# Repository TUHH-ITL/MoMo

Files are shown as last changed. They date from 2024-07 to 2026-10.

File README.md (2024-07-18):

# MoMo

This is the repository of **MoMo**: An Open-Source **Mo**dular **Mo**bile Robot.

Find more information about MoMo in the [official documentation](https://tuhh-itl.github.io/MoMo/).

## License

The codes and files in this repository are under the [3-Clause BSD License](https://opensource.org/license/bsd-3-clause).

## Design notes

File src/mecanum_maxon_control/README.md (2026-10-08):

# Mecanum Maxon control

This package converts ROS 2 `geometry_msgs/Twist` commands on `/cmd_vel` to four
Maxon EPOS4 profile-velocity targets through `ros2_canopen`.

Wheel order and CAN node mapping:

1. front-left (`cia402_device_1`)
2. front-right (`cia402_device_2`)
3. rear-left (`cia402_device_3`)
4. rear-right (`cia402_device_4`)

The checked-in controller configuration contains the dimensions, 21:1 gearbox
ratio, node order, and motor directions verified on this MoMo robot.
The motor command clamp is 3000 RPM (about 1.50 m/s straight-line speed), below
the 3170 RPM maximum profile velocity configured in all four EPOS4 DCF files.

## Build

The matching `ros2_canopen` source is vendored in this workspace at
`src/ros2_canopen`. No files outside this workspace are needed at build time or
runtime.

Install the native build and teleoperation dependencies once:

```bash
sudo apt update
sudo apt install -y libtool libtool-bin libboost-all-dev \
  ros-jazzy-diagnostic-updater ros-jazzy-joy ros-jazzy-teleop-twist-joy
```

```bash
cd /home/itlbot2/ros2_jazzy
source /opt/ros/jazzy/setup.bash
# Overlay any packages already built in this workspace.
source install/setup.bash 2>/dev/null || true
colcon build --symlink-install \
  --base-paths src/ros2_canopen src/mecanum_maxon_control \
  --packages-up-to mecanum_maxon_control \
  --cmake-clean-cache
source install/setup.bash
```

Source `/opt/ros/jazzy/setup.bash` first in every new terminal. Otherwise CMake
cannot discover system ROS packages such as `diagnostic_updater`.

## CAN and launch

### After every PC reboot

`can0` is now brought up automatically by the systemd unit checked in at
`systemd/can0-up.service` in this package. It is bound to the udev-generated
device unit for the Kvaser adapter (`sys-subsystem-net-devices-can0.device`),
so it runs on every boot and every hotplug/replug of the adapter, configuring
`can0` at 1 Mbit/s with `restart-ms 100` before anything else needs it. No
manual step is required before launching ROS 2.

Install it on a new PC with:

```bash
sudo cp systemd/can0-up.service /etc/systemd/system/can0-up.service
sudo systemctl daemon-reload
sudo systemctl enable --now can0-up.service
```

Check it came up correctly:

```bash
systemctl status can0-up.service
ip -details -statistics link show can0
```

The last command must show `can0` as `UP` and bitrate `1000000`. If `can0` does
not exist at all, verify the Kvaser USB adapter is connected
(`lsusb | grep -i kvaser`), then run `sudo modprobe kvaser_usb`.

To force a manual re-bounce of the interface (e.g. after a CAN bus fault),
either restart the unit or run the equivalent commands directly:

```bash
sudo systemctl restart can0-up.service
# equivalent to:
sudo ip link set can0 down 2>/dev/null || true
sudo ip link set can0 type can bitrate 1000000 restart-ms 100
sudo ip link set can0 up
ip -details -statistics link show can0
```

No separate EPOS4 initialization command is required. The launch file resets,
configures, starts, and enables all four CANopen drives. Once `can0` is up, launch:

```bash
source /opt/ros/jazzy/setup.bash
source /home/itlbot2/MoMo/install/setup.bash
ros2 launch mecanum_maxon_control mecanum_drive.launch.py
```

Wait for this message before publishing `/cmd_vel`:

```text
All four EPOS4 drives initialized in profile velocity mode
```

The CANopen container needs raw SocketCAN access (`CAP_NET_RAW`/`CAP_NET_ADMIN`),
granted via a file capability on the built binary rather than running the whole
launch as root. Without it, `device_container_node` aborts on startup with
`CanController: Operation not permitted`.

Running everything as your normal user (instead of `sudo -E`) matters beyond
convenience: DDS discovery breaks across UIDs. FastDDS's shared-memory
transport creates separate `/dev/shm/fastrtps_*` segments per user, so
root-launched nodes and non-root `ros2` CLI tools (`ros2 node list`,
`ros2 topic echo`, `rqt`, etc.) silently can't see each other even though data
still flows fine *between* same-UID nodes.

**The capability must be re-applied after every rebuild** of `canopen_core`
(colcon reinstalling the binary wipes the capability bit — this happens even
with `--symlink-install`, since that flag symlinks scripts/config but still
*copies* compiled executables). This is now automatic:
`canopen_core/CMakeLists.txt` runs
`canopen_core/scripts/set_can_capabilities.sh` via `install(CODE ...)`,
directly on `install/canopen_core/lib/canopen_core/device_container_node`
once that file exists at its final path.

The script calls `sudo -n setcap` (non-interactive), so it needs a one-time
NOPASSWD sudoers rule scoped to that exact command on a new machine:

```bash
echo "$USER ALL=(root) NOPASSWD: /usr/sbin/setcap cap_net_admin,cap_net_raw+ep $(pwd)/../../install/canopen_core/lib/canopen_core/device_container_node" \
  | sudo EDITOR='tee -a' visudo -f /etc/sudoers.d/momo-can-capabilities
sudo visudo -c
```
(run from `src/mecanum_maxon_control`, or substitute the absolute install
path directly). `visudo -c` must report "parsed OK" — if not, remove
`/etc/sudoers.d/momo-can-capabilities` and fix it before doing anything else,
since a broken sudoers file can lock out `sudo` entirely.

Without that sudoers rule the build still succeeds — the script just prints a
warning and leaves the binary without the capability, same failure as before.
Verify manually any time with:

```bash
getcap install/canopen_core/lib/canopen_core/device_container_node
```

File capabilities put the binary into the dynamic linker's "secure-execution
mode" (the same rule as setuid binaries), which makes `ld.so` **ignore
`LD_LIBRARY_PATH`** — so `device_container_node` can no longer find workspace
libraries (e.g. `libcanopen_interfaces__rosidl_generator_c.so`) through the
`LD_LIBRARY_PATH` that `install/setup.bash` sets. Fixed by registering every
built package's `lib/` dir with `ldconfig` instead, which isn't an env var and
works regardless of secure-execution mode:

```bash
find /home/itlbot2/MoMo/install -mindepth 2 -maxdepth 2 -type d -name lib | sort \
  | sudo tee /etc/ld.so.conf.d/momo-ros2.conf
sudo ldconfig
```

Re-run this whenever a **new package** (not just a rebuilt one) is added to
the workspace, so its `lib/` dir gets picked up too.

Initial PDO setup can take about 30 seconds; the `cmd_vel` controller starts
after a 45-second safety delay.

Test at low speed with all wheels clear of the floor:

```bash
ros2 topic pub --once /cmd_vel geometry_msgs/msg/Twist \
  "{linear: {x: 0.05, y: 0.0}, angular: {z: 0.0}}"
```

The controller latches the last velocity until a new command arrives. The joystick
teleoperation node sends a zero command when its enable button is released, so the
robot stops even though the underlying controller uses latched commands.

### Logitech F710 joystick

Connect the F710 USB receiver, put the switch on the front of the gamepad in `X`
(XInput) mode, and turn the gamepad on. Verify Linux can see it before launching:

```bash
lsusb | grep -i logitech
ls -l /dev/input/js*
```

The configuration is taken from the original MoMo backup:

- Hold **LB** (button 4) for normal driving (up to 1.0 m/s and 1.5 rad/s).
- Hold **RB** (button 5) for turbo driving (up to 1.5 m/s and 2.0 rad/s).
- Left stick up/down controls forward/reverse (`linear.x`).
- Left stick left/right controls mecanum strafing (`linear.y`).
- Right stick left/right controls rotation (`angular.z`).
- Release LB or RB to stop.

The launch file starts CANopen motor control, the joystick driver, and the joystick
to `/cmd_vel` converter together. Run it instead of `mecanum_drive.launch.py`:

```bash
source /opt/ros/jazzy/setup.bash
source /home/itlbot2/MoMo/install/setup.bash
ros2 launch mecanum_maxon_control mecanum_teleop.launch.py
```

Wait for `All four EPOS4 drives initialized in profile velocity mode` before
driving. If `/dev/input/js0` is absent, reconnect the receiver, confirm the pad is
in X mode, and press a gamepad button. The ROS 2 joystick driver selects joystick
device 0 by default.

### Changing joystick speed

Joystick speed is controlled in
`mecanum_maxon_control/config/teleop_joy.yaml`:

- `scale_linear.x` and `scale_linear.y` are the LB translation limits in m/s.
- `scale_angular.yaw` is the LB rotation limit in rad/s.
- `scale_linear_turbo.x` and `scale_linear_turbo.y` are the RB turbo
  translation limits in m/s.
- `scale_angular_turbo.yaw` is the RB turbo rotation limit in rad/s.

The controller also applies a final motor-speed ceiling using `max_motor_rpm` in
`mecanum_maxon_control/config/controller.yaml`. With the configured 21:1 gearbox
and 0.10 m wheel radius, 1000 motor RPM is approximately 0.50 m/s and the current
3000 RPM limit is approximately 1.50 m/s. Increasing only the joystick scales
above that limit will not make the wheels turn faster.

Do not set `max_motor_rpm` above the EPOS4 `max profile velocity` of 3170 RPM
configured in the four motor DCF files. After changing either YAML file, rebuild
and restart the launch file:

```bash
cd /home/itlbot2/ros2_jazzy
source /opt/ros/jazzy/setup.bash
source install/setup.bash
colcon build --symlink-install --packages-select mecanum_maxon_control
source install/setup.bash
```

Acceleration and stopping response are controlled by `max_wheel_acceleration`
and `max_wheel_deceleration` in `config/controller.yaml`, with the corresponding
EPOS profile objects `0x6083` and `0x6084` in
`config/maxon_mecanum_bus/bus.yml`. Both currently correspond to approximately
10000 motor RPM/s, giving approximately 0.3 seconds to reach maximum speed or
stop from it. Keep each software limit consistent with its EPOS limit when
tuning the response.

These 10000 RPM/s acceleration and deceleration values were tested on the MoMo
robot and produced responsive driving without the previous slow takeoff or the
wheels continuing to spin after releasing the joystick. For reference, the old
2000 RPM/s values took approximately 1.5 seconds to accelerate to or stop from
the 3000 RPM maximum. Test future changes with the wheels clear of the floor
before driving on the ground.

For keyboard control, leave `mecanum_drive.launch.py` running and use:

```bash
ros2 run teleop_twist_keyboard teleop_twist_keyboard
```

Use `k` or the space bar to send zero velocity and stop the robot.

Mecanum strafing uses `linear.y`; forward/reverse uses `linear.x`; rotation uses
`angular.z`.

## LED / speaker status indicator

`arduino_status_indicator.py` runs alongside the drive controller (launched by
`mecanum_drive.launch.py`) and drives the robot's LED strips and speaker
Arduino (`src/arduino/main`) over USB serial. It replaces the old behavior
where the Arduino played "Ich bin bereit" the instant it got power and ran a
decorative rainbow animation instead of showing anything meaningful.

There are two independent color sources, and the Arduino's own hardware
sensing always wins over ROS:

- **Hardware layer** (local to the Arduino sketch): reads the two
  battery-watcher pins directly and forces RED (shutdown/e-stop) or ORANGE
  (battery warning), regardless of what ROS is doing.
- **ROS layer** (this node): only shown while the hardware layer reports "no
  alarm". Reflects the `mission_control` state machine's active features.

The node subscribes to:

- `motors_ready` (published by `mecanum_epos4_controller.py` once all four
  EPOS4 drives are initialized) — sends `'R'` once so the Arduino announces
  "Ich bin bereit" at the right time instead of immediately on power-up.
- `mission_control/state_change` — maps `active_features` to a single color
  byte, checked in priority order:

| Active feature | Byte sent | Color | Meaning |
|---|---|---|---|
| `gentle_stop` | `'E'` | RED | safety stop (obstacle / software e-stop) |
| `accept_remote_drive_commands` | `'B'` | BLUE | joystick/teleop has control |
| `command_movement` | `'G'` | GREEN | actively driving a mission |
| *(none of the above)* | `'Y'` | YELLOW | idle, paused, or waiting for controller |

Before the state machine has published anything at all, the Arduino defaults
to **WHITE** on its own (no byte needs to be sent for this — it's the
sketch's power-on default), so the LEDs never silently show green before the
robot is actually doing anything.

Configured via the `status_indicator_port` launch argument (default
`/dev/ttyArduinoStatus`, `mecanum_drive.launch.py`). No udev rule exists yet
for this Arduino — add one under
`robotics_base/hardware_description/files/udev/`, following the existing
`44-rfid.rules`/`43-weighing_scale.rules` pattern, once the board's
`idVendor`/`idProduct` (and `serial` if it collides with another board) are
known from `udevadm info -a -n /dev/ttyACMx`. Until then the port name is
whatever the kernel assigns and can change across reboots/replugs.

## MoMo drivetrain calibration

The controller uses the dimensions and conversion from the original MoMo ROS 1
configuration: 0.10 m wheel radius, 0.54 m wheelbase, 0.58 m track width, and a
21:1 motor-to-wheel reduction. CANopen nodes 1 through 4 correspond to
front-left, front-right, rear-left, and rear-right respectively.

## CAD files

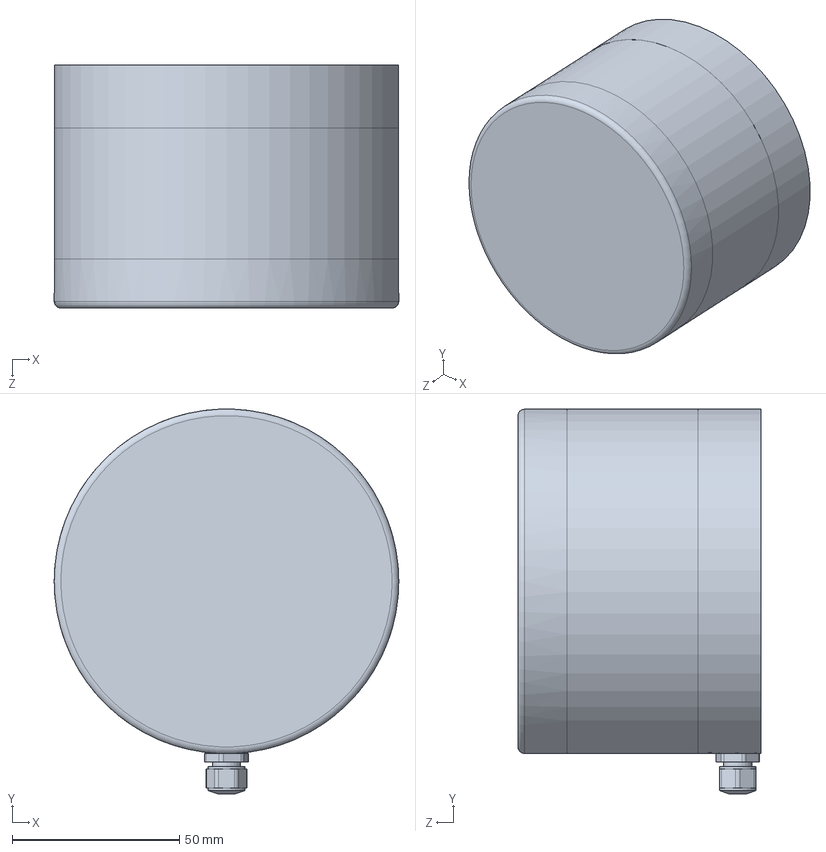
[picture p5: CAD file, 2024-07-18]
CAD/velodyne-vlp16.SLDPRT
103.0 x 115.1 x 72.7 mm

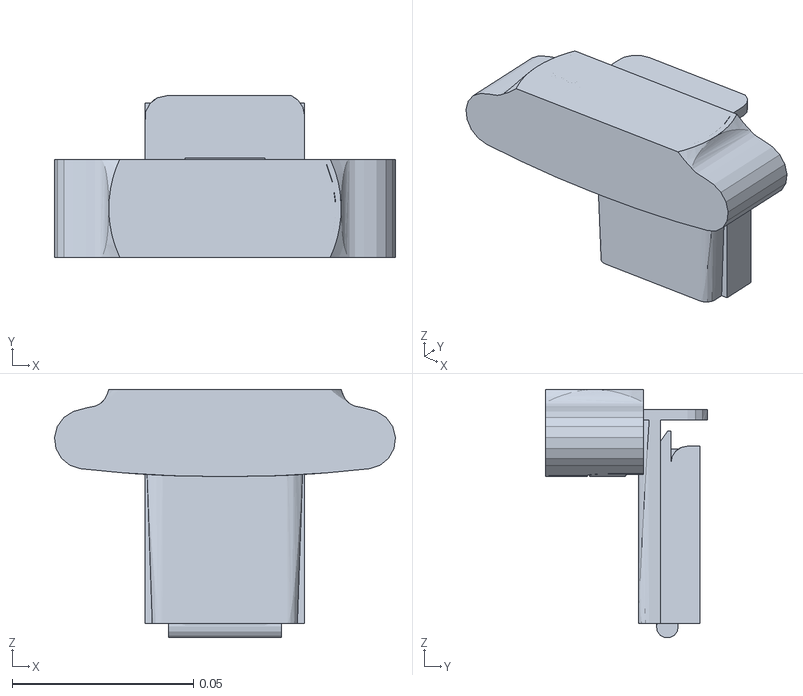
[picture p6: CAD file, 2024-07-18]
src/momo_description/meshes/collision/right_logitech.STL
0.094 x 0.0445 x 0.0684

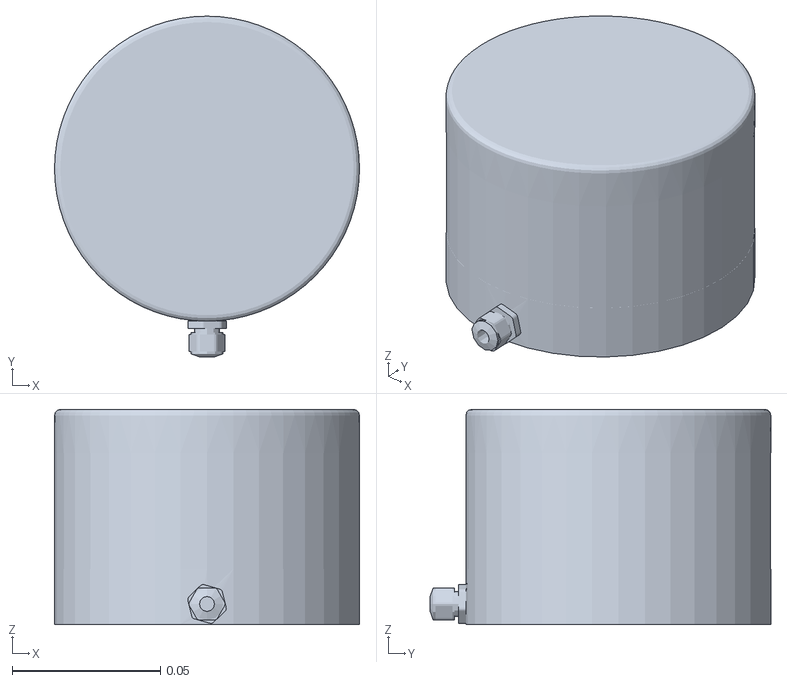
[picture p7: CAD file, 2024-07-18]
src/momo_description/meshes/visual/lidar.STL
0.103 x 0.115 x 0.0727

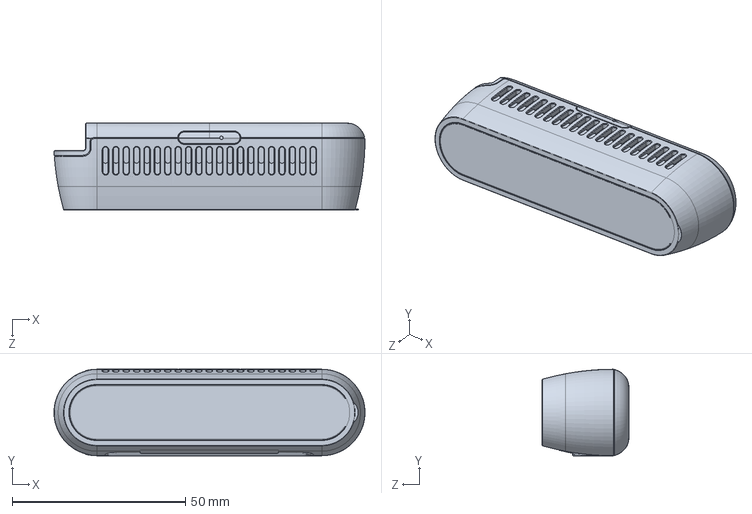
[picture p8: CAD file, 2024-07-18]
CAD/realsense_d435i.SLDPRT
89.9 x 25.0 x 25.1 mm

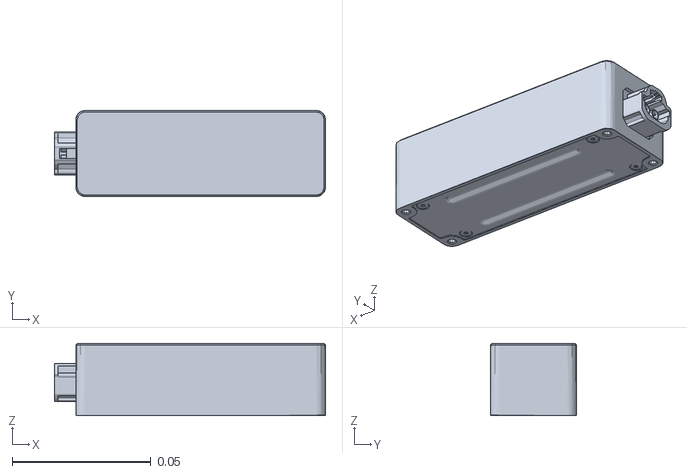
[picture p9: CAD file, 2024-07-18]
src/momo_description/meshes/collision/ifm_camera.STL
0.0977 x 0.031 x 0.026

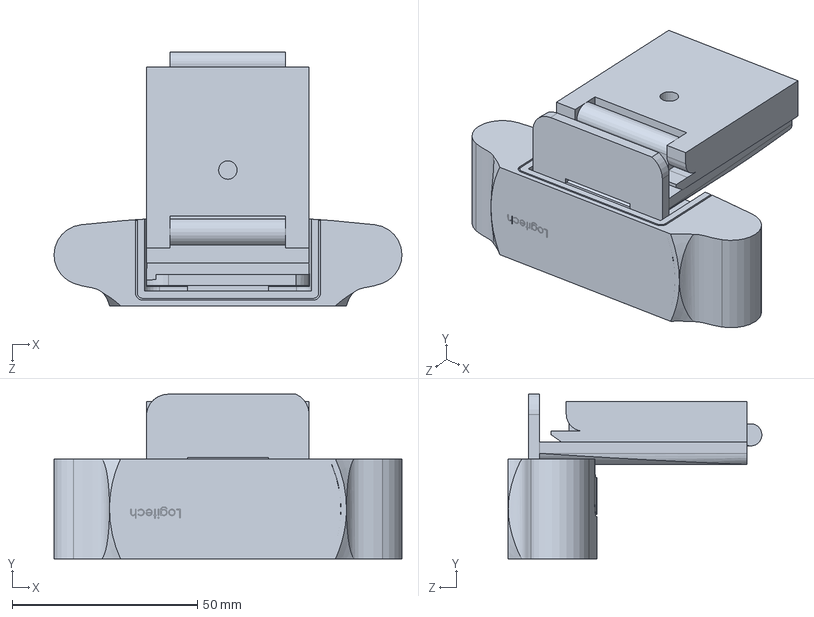
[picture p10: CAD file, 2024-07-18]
CAD/logitech_c920__link.SLDPRT
94.0 x 44.5 x 68.5 mm

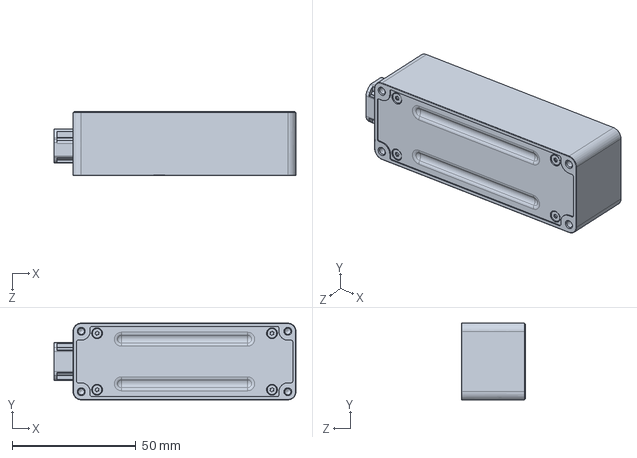
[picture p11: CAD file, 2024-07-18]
CAD/ifm_o3r222.SLDPRT
97.7 x 31.0 x 26.0 mm

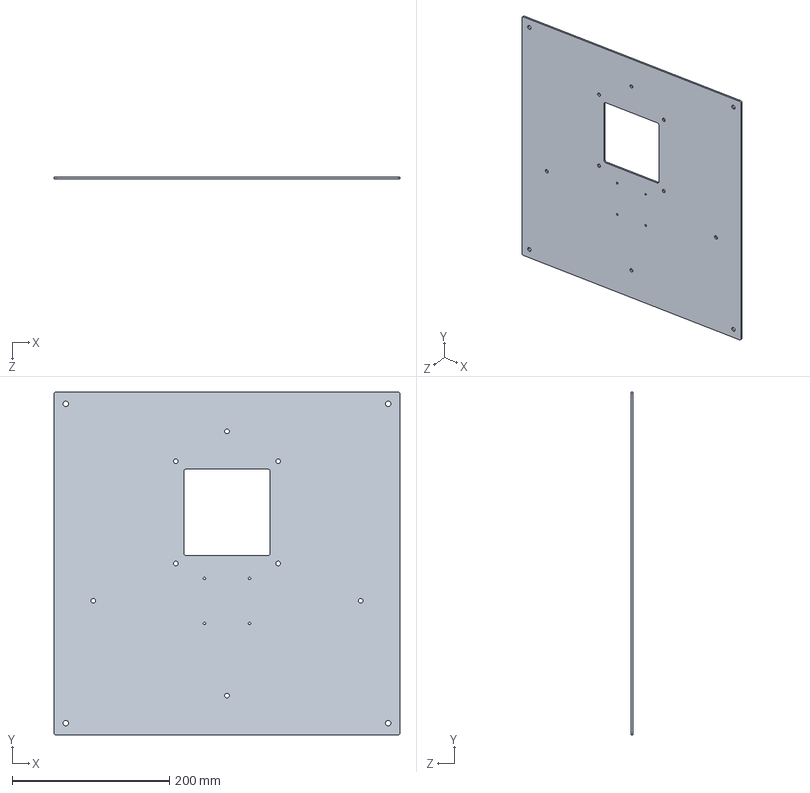
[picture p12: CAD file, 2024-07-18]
CAD/top_plate_localization_module.SLDPRT
440.0 x 436.0 x 3.00 mm

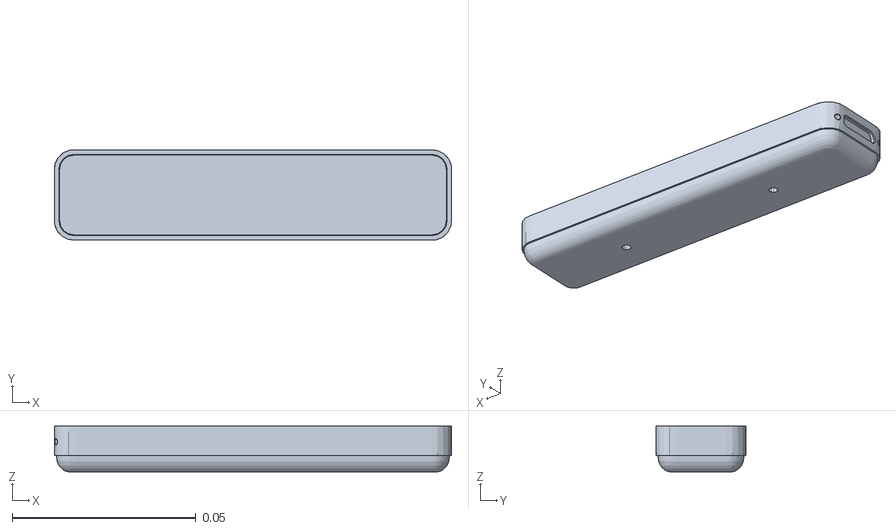
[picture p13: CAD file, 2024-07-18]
src/momo_description/meshes/visual/realsense_t265.STL
0.108 x 0.0245 x 0.0125

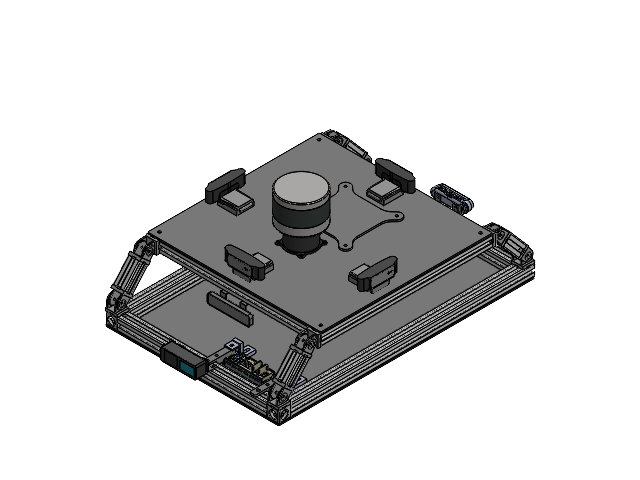
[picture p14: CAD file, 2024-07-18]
CAD/Assemblies/localization-module.SLDASM
base_plate_localization_module
cube_connector x 2
Aluminium_profile_620 x 2
Aluminium_profile_380 x 4
joint_30 x 16
Aluminium_profile_60 x 4
Aluminium_profile_436 x 2
top_plate_localization_module
cover_top_plate
velodyne_mount
velodyne-vlp16
logitech_c920__link x 4
realsense_mounting_bracket x 6
ifm_o3r222
realsense_t265
realsense_d435i
Mount_Harting_Connector x 2
Harting_Modular_Connector_upper_part
Aluminium_angle_bracket x 4
angle_5_20 x 2
mounting_bracket x 2

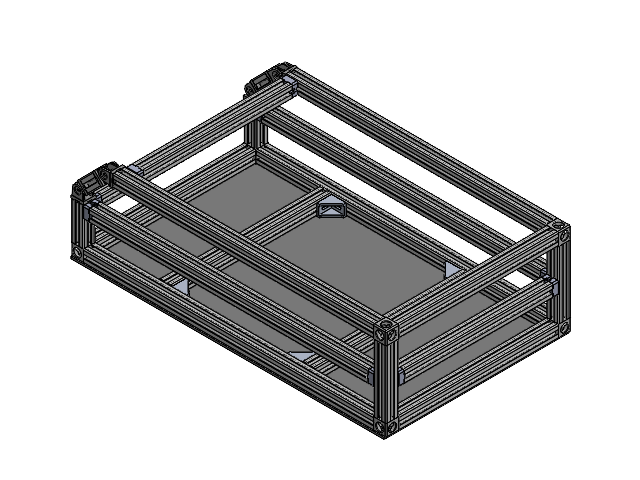
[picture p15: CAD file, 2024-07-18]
CAD/Assemblies/momo_frame.SLDASM
base_link
cube_connector x 6
Aluminium_profile_690 x 2
Aluminium_profile_380 x 5
Aluminium_profile_160 x 2
connector x 10
Aluminium_profile_664 x 2
Aluminium_profile_90 x 2
joint_30 x 8
Aluminium_profile_42_8 x 2
Aluminium_profile_620 x 2
Aluminium_profile_354 x 3
Aluminium_angle_bracket x 4

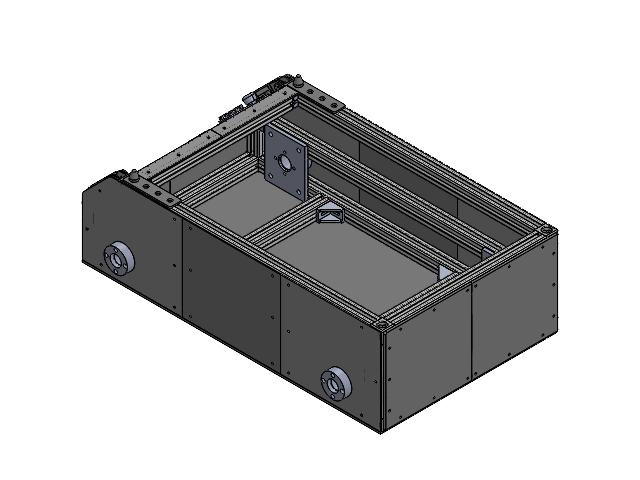
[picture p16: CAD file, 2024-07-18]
CAD/Assemblies/momo_body.SLDASM
base_link
cube_connector x 6
Aluminium_profile_690 x 2
Aluminium_profile_380 x 5
Aluminium_profile_160 x 2
connector x 10
Aluminium_profile_664 x 2
Aluminium_profile_90 x 2
joint_30 x 8
Aluminium_profile_42_8 x 2
Aluminium_profile_620 x 2
Aluminium_profile_354 x 3
Aluminium_angle_bracket x 4
back_wheel_cover x 2
center_cover x 2
front_wheel_cover x 2
back_cover x 2
front_left_panel
front_right_panel
cover_with_connections
screen_holder
Spacer x 2
Centering_Cone x 2
motor_holder x 4
emergency-button
press-switch
dummy_screen
dummy-voltage-meter
dummy-usb-port x 3
dummy-etherCAT6
dummy-connectors

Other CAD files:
src/momo_description/meshes/collision/front_logitech.STL
src/momo_description/meshes/collision/back_logitech.STL
src/momo_description/meshes/visual/back_logitech.STL
src/momo_description/meshes/collision/left_logitech.STL
CAD/Aluminium_angle_bracket.SLDPRT
CAD/Aluminium_profile_160.SLDPRT
CAD/Aluminium_profile_30.SLDPRT
CAD/Aluminium_profile_354.SLDPRT
CAD/Aluminium_profile_380.SLDPRT
CAD/Aluminium_profile_42_8.SLDPRT
CAD/Aluminium_profile_436.SLDPRT
CAD/Aluminium_profile_60.SLDPRT
CAD/Aluminium_profile_620.SLDPRT
CAD/Aluminium_profile_664.SLDPRT
CAD/Aluminium_profile_690.SLDPRT
CAD/Aluminium_profile_89.SLDPRT
CAD/Aluminium_profile_90.SLDPRT
CAD/Centering_Cone.SLDPRT
CAD/Harting_Modular_Connector_upper_part.SLDPRT
CAD/Joint_30x30.SLDPRT
CAD/Mount_Harting_Connector.SLDPRT
CAD/Spacer.SLDPRT
CAD/angle_5_20.SLDPRT
CAD/back_cover.SLDPRT
CAD/back_wheel_cover.SLDPRT
CAD/base_link.SLDPRT
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

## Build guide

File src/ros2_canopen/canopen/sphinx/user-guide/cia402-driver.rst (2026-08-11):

Cia402 Driver
========================

The Cia402 Driver implements the CIA402 profile for motion controllers and enables setting
the drive status, operation mode and sending target values to the motion controller.

.. csv-table:: CIA402 Drivers
   :header: Type, Package, Name
   :widths: 30, 20, 50

   lifecycle, canopen_402_driver, ros2_canopen::LifecycleCia402Driver
   simple, canopen_402_driver, ros2_canopen::Cia402Driver

Services
--------

.. list-table::
  :widths: 30 20 50
  :header-rows: 1
  :align: left

  * - Services
    - Type
    - Description
  * - ~/nmt_reset_node
    - Trigger
    - Resets CANopen Device the Proxy Device Node manages.
  * - ~/sdo_read
    - CORead
    - Reads an SDO object from the specified index, subindex and datatype of the remote device.
  * - ~/sdo_write
    - COWrite
    - Writes data to an SDO object on the specified index, subindex and datatype of the remote device.
  * - ~/init
    - Trigger
    - Initialises motion controller including referencing
  * - ~/recover
    - Trigger
    - Recovers motion controller
  * - ~/halt
    - Trigger
    - Stops motion controller
  * - ~/position_mode
    - Trigger
    - Switches to profiled position mode
  * - ~/velocity_mode
    - Trigger
    - Switches to profiled velocity mode
  * - ~/torque_mode
    - Trigger
    - Switches to profiled torque mode
  * - ~/cyclic_position_mode
    - Trigger
    - Switches to cyclic position mode
  * - ~/cyclic_velocity_mode
    - Trigger
    - Switches to cyclic velocity mode
  * - ~/cyclic_torque_mode
    - Trigger
    - Switches to cyclic torque mode
  * - ~/interpolated_position_mode
    - Trigger
    - Switches to interpolated position mode, only linear mode with fixed time is supported
  * - ~/target
    - CODouble
    - Sets the target value. Only accepted when an operation mode is set.

Publishers
----------
.. list-table::
  :widths: 30 20 50
  :header-rows: 1
  :align: left

  * - Publishers
    - Type
    - Description
  * - ~/joint_states
    - sensor_msgs/msg/JointState
    - Joint states of the drive
  * - ~/nmt_state
    - String
    - Publishes NMT state on change
  * - ~/rpdo
    - COData
    - Publishes received PDO objects on reception

Subscribers
-----------

.. list-table::
  :widths: 30 20 50
  :header-rows: 1

  * - Topic
    - Type
    - Description
  * - ~/target
    - COTargetDouble
    - Sets target value.
  * - ~/tpdo
    - COData
    - Writes received data to remote device if the specified object is RPDO mapped on remote device.

Bus Configuration Parameters
----------------------------
Additional parameters that can be used in bus.yml for this driver.

.. list-table::
  :widths: 30 20 50
  :header-rows: 1

  * - Parameter
    - Type
    - Description
  * - polling
    - bool
    - Enables polling of the drive status. Default: true. If false, period will be used to run a ros2 timer as update loop. If true, the update loop will be triggered by the sync signal and directly executed in the canopen realtime loop. This requires all data processed in the update loop to be PDO, otherwise the loop will get stuck. This can speed reduce processor load significantly though.
  * - period
    - Milliseconds
    - Refresh period for 402 state machine. Should be similar to sync period of master.
  * - switching_state
    - see below
    - The state to switch the operation mode in.
  * - scale_pos_to_dev
    - double
    - Scaling factor to convert from SI units to device units for position.
  * - offset_pos_to_dev
    - double
    - Offset in device units added to scaled position commands sent to the device.
  * - scale_vel_to_dev
    - double
    - Scaling factor to convert from SI units to device units for velocity.
  * - scale_pos_from_dev
    - double
    - Scaling factor to convert from device units to SI units for position.
  * - offset_pos_from_dev
    - double
    - Offset in SI units to added to scaled position reports from the device.
  * - scale_vel_from_dev
    - double
    - Scaling factor to convert from device units to SI units for velocity.
  * - position_mode
    - int
    - The drives operation mode to use for the position interface
  * - velocity_mode
    - int
    - The drives operation mode to use for the velocity interface
  * - torque_mode
    - int
    - The drives operation mode to use for the torque interface

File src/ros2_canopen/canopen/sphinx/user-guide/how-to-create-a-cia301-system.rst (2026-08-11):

How to create a cia301 system with ros2_control
=================================================

The CiA 301 profile, also known as the CANopen application layer,
is the foundation of the CANopen protocol. It defines the basic principles,
communication services, and object dictionary used for device communication
and network management in a CANopen system.

The CiA 301 profile defines several communication services that allow devices
to exchange data and perform actions. These services include
the SDO (Service Data Object) service for transferring object data between devices,
the PDO (Process Data Object) service for real-time data exchange,
and the NMT (Network Management) service for network initialization,
device state control, and error handling.

To bring up the CiA301 interface using ROS2, it includes three steps:

- preparing the configuration for bus and ``ros2_control``
- preparing the state and command interfaces,
- and finally preparing the launch file.

Preparing the configuration
--------------------------------------------------------
To use the control system interface for CiA301 profile, we should prepare the following

- bus_conf
- master_dcf
- master_bin
- can_interface, (default: vcan0)

Define the bus configuration parameters

.. code-block:: yaml

    master:
        node_id: 1
        driver: "ros2_canopen::MasterDriver"
        package: "canopen_master_driver"
        baudrate: 250
    options:
        dcf_path: "@BUS_CONFIG_PATH@"
    joint_1:
        node_id: 0x00
        dcf: "joint.eds"
        driver: "ros2_canopen::ProxyDriver"
        package: "canopen_proxy_driver"
        reset_communication: false
    joint_2:
        node_id: 0x01
        dcf: "joint.eds"
        driver: "ros2_canopen::ProxyDriver"
        package: "canopen_proxy_driver"
        reset_communication: false

Define the ``ros2_control`` parameters

.. code-block:: yaml

    controller_manager:
        ros__parameters:
            update_rate: 100  # Hz

            joint_state_broadcaster:
                type: joint_state_broadcaster/JointStateBroadcaster

            joint_1_controller:
                type: canopen_ros2_controllers/CanopenProxyController

            joint_2_controller:
                type: canopen_ros2_controllers/CanopenProxyController

        joint_1_controller:
            ros__parameters:
                joint: joint_1

       joint_2_controller:
            ros__parameters:
                joint: joint_2

The example of master_dcf see https://github.com/ros-industrial/ros2_canopen/blob/master/canopen_tests/config/simple/simple.eds

Use RPDO to access the current state
--------------------------------------------------------
Defining the Joint and CANopen Data Structure
 The first step is to define a structure that will hold information about your joints and the associated CANopen data. This structure serves as the foundation for  your CANopen network, ensuring that all the relevant data is stored and accessible when needed.

PDO Index and Subindex
 Each Process Data Object (PDO) has an index and a subindex. The index acts as a unique identifier for each PDO, differentiating it from other PDOs in the system. The subindex is used to access individual data fields within each PDO as a PDO can contain multiple data fields.

Network Management (NMT)
 Network Management (NMT) is a fundamental service in the CANopen protocol suite. It offers basic device control commands such as start, stop, and reset, and manages the state of devices within the network.

 For RPDOs, the data are defined using:

 - "rpdo/index"
 - "rpdo/subindex"
 - "rpdo/type"
 - "rpdo/data"

 For NMT, we can read the states via:

 - "nmt/state"

Use TPDO to send commands
----------------------------
In order to send commands to hardware devices in a CANopen network, we first need to export the appropriate hardware interfaces. This is a critical step that enables us to effectively control each joint within our network.

Registering Transmit Process Data Objects (TPDOs)
 Similar to how we handle state interfaces, we must register Transmit Process Data Objects (TPDOs) for each joint. These TPDOs are related to the following commands:

- "tpdo/index"
- "tpdo/subindex"
- "tpdo/type"
- "tpdo/data"
- "tpdo/owns"

Network Management (NMT) Commands
 Beyond this, we have the ability to register commands associated with Network Management (NMT) to control the state of devices within our network. This is important for the smooth operation and control of our devices. The NMT related commands include:

- "nmt/reset"
- "nmt/reset_fbk"
- "nmt/start"
- "nmt/start_fbk"

These NMT commands not only help in managing the state of devices but also in providing feedback (indicated by "fbk") from the device to the control system after the execution of a command. This feedback mechanism is crucial for ensuring the successful execution of commands and managing the overall health of the network.

How to launch the nodes
----------------------------
Finally, we prepare the launch file for the interface. An example see: https://github.com/ros-industrial/ros2_canopen/blob/master/canopen_ros2_control/launch/canopen_system.launch.py

For testing, please refer to following section.

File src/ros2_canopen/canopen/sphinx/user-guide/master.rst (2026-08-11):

Master Driver
=============

The master driver handles the creation of the necessary can interface and sets up a canopen event loop which drivers can hook onto.
In addition, the node offers services for communicating with nodes via nmt and sdo.

.. csv-table:: Master Drivers
   :header: Type, Package, Name
   :widths: 30, 20, 50

   lifecycle, canopen_master_driver, ros2_canopen::LifecycleMasterDriver
   simple, canopen_master_driver, ros2_canopen::MasterDriver

Services
--------

.. list-table::
  :widths: 30 20 50
  :header-rows: 1

  * - Services
    - Type
    - Description
  * - ~/read_sdo
    - COReadID
    - Reads an SDO object specified by Index, Subindex and Datatype of the device with the specified nodeid.
  * - ~/write_sdo
    - COWriteID
    - Writes Data to an SDO object specified by Index, Subindex and Datatype on the device with the specified nodeid.
  * - ~/set_nmt
    - CONmtID
    - Sends the NMT command to the device with the specified nodeid

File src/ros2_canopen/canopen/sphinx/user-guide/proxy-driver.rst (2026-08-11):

Proxy Driver
===================
A proxy driver which simply forwards CANopen functionality for a specific device via ROS2 services and messages.

.. csv-table:: Proxy Drivers
   :header: Type, Package, Name
   :widths: 30, 20, 50

   lifecycle, canopen_proxy_driver, ros2_canopen::LifecycleProxyDriver
   simple, canopen_proxy_driver, ros2_canopen::ProxyDriver

Services
--------

.. list-table::
  :widths: 30 20 50
  :header-rows: 1
  :align: left

  * - Services
    - Type
    - Description
  * - ~/nmt_reset_node
    - Trigger
    - Resets CANopen Device the Proxy Device Node manages.
  * - ~/sdo_read
    - CORead
    - Reads an SDO object from the specified index, subindex and datatype of the remote device.
  * - ~/sdo_write
    - COWrite
    - Writes data to an SDO object on the specified index, subindex and datatype of the remote device.

Publishers
----------

.. list-table::
  :widths: 30 20 50
  :header-rows: 1
  :align: left

  * - Topic
    - Type
    - Description
  * - ~/nmt_state
    - String
    - Publishes NMT state on change
  * - ~/rpdo
    - COData
    - Publishes received PDO objects on reception

Subscribers
-----------

.. list-table::
  :widths: 30 20 50
  :header-rows: 1

  * - Topic
    - Type
    - Description
  * - ~/tpdo
    - COData
    - Writes received data to remote device if the specified object is RPDO mapped on remote device.

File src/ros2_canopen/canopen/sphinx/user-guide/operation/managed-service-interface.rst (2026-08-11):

Managed Service Interface
============================

Device Container with managed nodes
"""""""""""""""""""""""""""""""""""
The device container implements ROS2 component manager. The load and unload services are disabled.
Devices are loaded based on the Bus Configuration File (bus.yml). The device container provides
the list service, which can be used with ros2cli to check which components have been loaded.

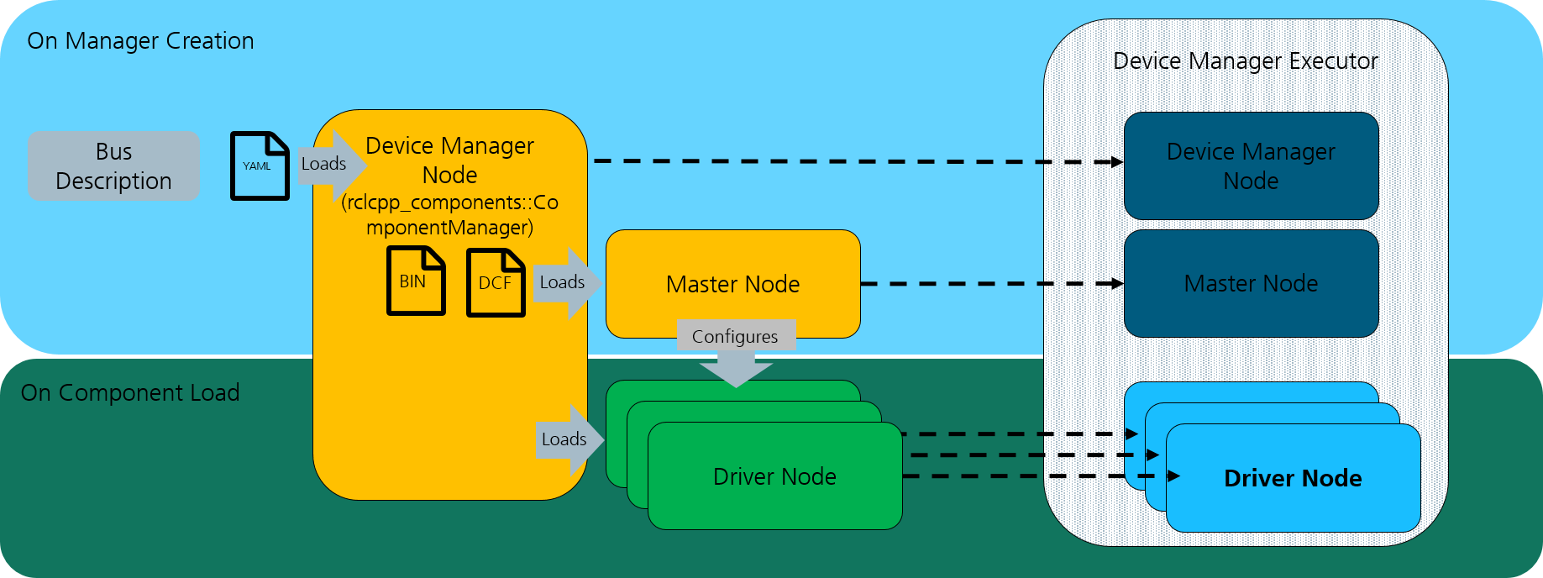
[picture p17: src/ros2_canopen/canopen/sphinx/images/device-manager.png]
Device Manager Concept


    device manager concept

The device container uses the bus description file to identify the correct drivers for each devices.
On launch it will load the CANopen master node and driver nodes and pass the appropriate configuration
data to the nodes. The nodes are now in unconfigured state.

When using the default launch files in canopen_core the lifecycle manager node will automatically
be launched. The lifecycle manager takes care of sequencing the lifecycle of the different nodes in the
device container. By bringing the lifecycle_manager to active lifecycle state, all master and driver nodes
will be activated in correct sequence.

If you choose to write your own lifecycle_manager, you'll need to remember, that the master needs
to be configured and activated before any driver node can be configured or activated.

Bus Configuration
"""""""""""""""""
The bus configuration for the managed service interface needs to use the driver classes that are marked as
lifecycle drivers. The master driver indicates whether the bus.yml will be treated as managed or un-managed
service interface.

.. csv-table:: Available Driver Components
   :header: "Package", "Component"

    canopen_master_driver, ros2_canopen::LifecycleMasterDriver
    canopen_proxy_driver, ros2_canopen::LifecycleProxyDriver
    canopen_402_driver, ros2_canopen::LifecycleCia402Driver

Launching
"""""""""""""
The device manager has the following configuration parameters.

.. csv-table:: Parameters
   :header: "Parameter", "Type", "Description"

    bus_conf, string, (Mandatory) Path to the bus configuration YAML-file
    master_dcf, string, (Mandatory) Path to the DCF file to be used by the master node. Usually generated by dcfgen as master.dcf.
    master_bin, string, (Optional) Path to the concise DCF (.bin) file to be used to configure the master. Usually generated by dcfgen as master.bin. (default: "")
    can_interface_name, string, (Mandatory) Name of the CAN interface to be used. (default: vcan0)

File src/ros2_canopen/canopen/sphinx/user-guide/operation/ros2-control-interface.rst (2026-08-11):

Hardware Interface
------------------
This package provides multiple hardware interfaces for testing. Mainly the following:

- canopen_ros2_control/CanopenSystem: A system interface for ProxyDrivers
- canopen_ros2_control/Cia402System: A system interface for Cia402Drivers
- canopen_ros2_control/Cia402RobotSystem: A system interface for Cia402Drivers in a robot configuration (under development)

Robot System Interface
''''''''''''''''''''''

The robot system interface takes a number of inputs from the robot description (urdf).
It will make the Cia402Drivers available via the ros2_control hardware interface.
The bus has to still be defined in the bus.yml file. In the urdf you can the choose the
CANopen nodes that have a Cia402Driver attached to them.

The ros2_control interface only works with non-lifecycle drivers right now.
For each joint in your urdf you can choose the attached CANopen device by using the
``node_id`` parameter. The ``node_id`` parameter is the CANopen node id of the device.

.. code-block:: xml

    <ros2_control name="${name}" type="system">
        <hardware>
            <plugin>canopen_ros2_control/Cia402RobotSystem</plugin>
            <param name="bus_config">[path to bus.yml]</param>
            <param name="master_config">[path to master.dcf]</param>
            <param name="can_interface_name">[can interface to be used]</param>
            <param name="master_bin">[master.bin if it exists]</param>
        </hardware>
        <joint name="joint1">
            <param name="node_id">3</param>
            ...
        </joint>
        <joint name="joint2">
            <param name="node_id">3</param>
            ...
        </joint>
    </ros2_control>

.. note::

    You can find an example for the configuration in the ``canopen_tests`` package under robot_control.

ROS2 Controllers
----------------
This package provides multiple controllers for testing. Mainly the following:

- canopen_ros2_controllers/Cia402RobotController: Works with Robot System Interface
- canopen_ros2_controllers/Cia402DeviceController: Works with Cia402System
- canopen_ros2_controllers/CanopenProxyController: Works with CanopenSystem and Cia402System

Robot Controller
''''''''''''''''

The robot controller enables bringing up the different joints of the robot automatically
by using the ros2_controller lifecycle. There is no need for further action, once the
controller is activated, the drives are ready to be used.

The robot controller can be configured in the ros2_controllers.yaml with the following
parameters:

.. code-block:: yaml

    robot_controller:
        ros__parameters:
            joints:  # joints that are controlled by the controller
            - joint1
            - joint2
            operation_mode: 1 # operation mode of the controller
            command_poll_freq: 5 # frequency with which the controller polls for command feedback

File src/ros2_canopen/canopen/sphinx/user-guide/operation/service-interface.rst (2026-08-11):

Service Interface
==================

Device Container
"""""""""""""""""
The device container implements ROS2 component manager. The load and unload services are disabled.
Devices are loaded based on the Bus Configuration File (bus.yml). It provides the list service though.

Device Manager Concept

    device manager concept

The device manager uses the bus description file to identify the correct drivers for each devices.
On launch it will load the CANopen master node and pass the generated DCF files to configure the CANopen master
correctly for you bus configuration. It will the enable the master. Once the master is enabled it will
sequentially load and enable all drivers in the bus configuration.

Once a CANopen Node comes online (i.e. sends the boot indication) the CANopen master
will configure the node with the parameters and commands specified in the bus configuration for that device.
When the configuration of the device is done, all data send by the device is forwarded
to the appropriate driver.

All loaded nodes are added to the device manager's executor.

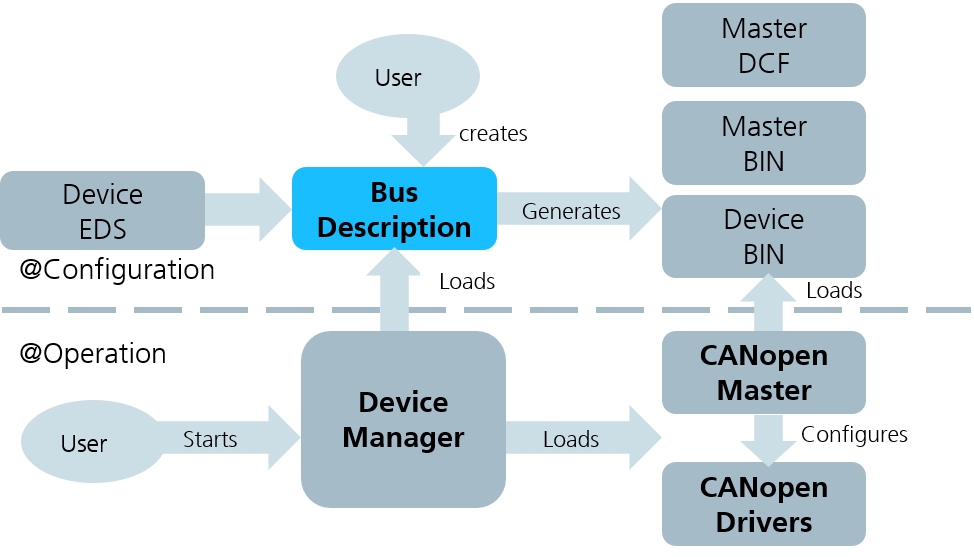
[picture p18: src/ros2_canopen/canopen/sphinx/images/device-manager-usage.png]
Device Manager Usage


    device manager usage

Bus Configuration
"""""""""""""""""
The bus configuration for the needs to use the driver classes that are marked as
non lifecycle drivers.

.. csv-table:: Available Driver Components
   :header: "Package", "Component"

    canopen_core, ros2_canopen::MasterDriver
    canopen_proxy_driver, ros2_canopen::ProxyDriver
    canopen_402_driver, ros2_canopen::Cia402Driver

Launching
"""""""""""""
The device manager has the following configuration parameters.

.. csv-table:: Parameters
   :header: "Parameter", "Type", "Description"

    bus_conf, string, (Mandatory) Path to the bus configuration YAML-file
    master_dcf, string, (Mandatory) Path to the DCF file to be used by the master node. Usually generated by dcfgen as master.dcf.
    master_bin, string, (Optional) Path to the concise DCF (.bin) file to be used to configure the master. Usually generated by dcfgen as master.bin. (default: "")
    can_interface_name, string, (Mandatory) Name of the CAN interface to be used. (default: vcan0)

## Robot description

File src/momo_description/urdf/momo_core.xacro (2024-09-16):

<?xml version="1.0"?>
<robot xmlns:xacro="http://www.ros.org/wiki/xacro">

    <!-- BASE_FOOTPRINT -->
    <link name="base_footprint">
        <visual>
            <origin xyz="0 0 0" rpy="0 0 0" />
            <geometry>
                <box size="0.001 0.001 0.001" />
            </geometry>
        </visual>
    </link>

    <joint name="base_footprint_joint" type="fixed">
        <origin xyz="0 0 0.001" rpy="0 0 0" />
        <parent link="base_footprint"/>
        <child link="base_link" />
    </joint>

    <!-- BASE LINK -->
    <link name="base_link">
        <inertial>
            <origin xyz="-0.0224834781318358 0.043147185108824 0.15573045535703" rpy="0 0 0" />
            <mass value="9.12874381762573" />
            <inertia ixx="0.0703209223004399" ixy="0.000823792790695999" ixz="0.000375834309002579" iyy="0.18869975254365" iyz="9.82268475527055E-07" izz="0.249106966997589" />
        </inertial>
        <visual>
            <origin xyz="0 0 0" rpy="0 0 0" />
            <geometry>
                <mesh filename="file://$(find momo_description)/meshes/visual/base_link.STL" />
            </geometry>
            <material name="">
                <color rgba="0.627450980392157 0.627450980392157 0.627450980392157 1" />
            </material>
        </visual>
        <collision>
            <origin xyz="0 0 0" rpy="0 0 0" />
            <geometry>
                <mesh filename="file://$(find momo_description)/meshes/visual/base_link.STL" />
            </geometry>
        </collision>
    </link>

    <gazebo reference="base_link">
        <material>Gazebo/Grey</material>
    </gazebo>

    <!-- FRONT RIGHT WHEEL -->
    <link name="front_right_wheel">
        <inertial>
            <origin xyz="0.00235002849639554 0.00303838901454816 -0.0804375311167912" rpy="0 0 0" />
            <mass value="0.852354605102217" />
            <inertia ixx="0.000906831105798678" ixy="9.81283854227688E-07" ixz="2.23619743963333E-11" iyy="0.000906168386374516" iyz="1.91429667110204E-11" izz="0.0010693441512525" />
        </inertial>
        <visual>
            <origin xyz="0 0 0.08" rpy="0 0 0" />
            <geometry>
                <mesh filename="file://$(find momo_description)/meshes/visual/front_right_wheel.STL" />
            </geometry>
            <material name="">
                <color rgba="0.792156862745098 0.819607843137255 0.933333333333333 1" />
            </material>
        </visual>
        <collision>
            <origin xyz="0 0 0.08" rpy="0 0 0" />
            <geometry>
                <mesh filename="file://$(find momo_description)/meshes/visual/front_right_wheel.STL" />
            </geometry>
        </collision>
    </link>

    <gazebo reference="front_right_wheel">
        <material>Gazebo/White</material>
    </gazebo>

    <joint name="front_right_wheel_joint" type="continuous">
        <!-- <origin xyz="0.26849 -0.318 0.059996" rpy="1.5708 0 0" /> -->
        <origin xyz="0.26849 -0.238 0.059996" rpy="1.5708 0 0" />
        <parent link="base_link" />
        <child link="front_right_wheel" />
        <axis xyz="0 0 -1" />
    </joint>

    <!-- BACK RIGHT WHEEL -->
    <link name="back_right_wheel">
        <inertial>
            <origin xyz="0.00235269913271367 0.00303881239038054 -0.0804375309775529" rpy="0 0 0" />
            <mass value="0.852354640622838" />
            <inertia ixx="0.000907345514266878" ixy="-5.98068915940485E-07" ixz="-2.00737014070952E-11" iyy="0.000905654311384346" iyz="8.48507848540578E-12" izz="0.00106934438027434" />
        </inertial>
        <visual>
            <origin xyz="0 0 0.08" rpy="0 0 0" />
            <geometry>
                <mesh filename="file://$(find momo_description)/meshes/visual/back_right_wheel.STL" />
            </geometry>
            <material name="">
                <color rgba="0.792156862745098 0.819607843137255 0.933333333333333 1" />
            </material>
        </visual>
        <collision>
            <origin xyz="0 0 0.08" rpy="0 0 0" />
            <geometry>
                <mesh filename="file://$(find momo_description)/meshes/visual/back_right_wheel.STL" />
            </geometry>
        </collision>
    </link>

    <gazebo reference="back_right_wheel">
        <material>Gazebo/White</material>
    </gazebo>

    <joint name="back_right_wheel_joint" type="continuous">
        <!-- <origin xyz="-0.27349334578749 -0.318000000000002 0.0599978846492716" rpy="1.5707963267949 0 0" /> -->
        <origin xyz="-0.27349334578749 -0.238 0.0599978846492716" rpy="1.5707963267949 0 0" />
        <parent link="base_link" />
        <child link="back_right_wheel" />
        <axis xyz="0 0 -1" />
    </joint>

    <!-- BACK LEFT WHEEL -->
    <link name="back_left_wheel">
        <inertial>
            <origin xyz="0.00235100431678491 0.00303777971566161 -0.00243588226510427" rpy="0 0 0" />
            <mass value="0.85235460510222" />
            <inertia ixx="0.000905522012701922" ixy="3.41693853969475E-07" ixz="-7.38335769311773E-12" iyy="0.000907477479471278" iyz="-2.84955602367874E-11" izz="0.00106934415125251" />
        </inertial>
        <visual>
            <origin xyz="0 0 0" rpy="0 0 0" />
            <geometry>
                <mesh filename="file://$(find momo_description)/meshes/visual/back_left_wheel.STL" />
            </geometry>
            <material name="">
                <color rgba="0.792156862745098 0.819607843137255 0.933333333333333 1" />
            </material>
        </visual>
        <collision>
            <origin xyz="0 0 0" rpy="0 0 0" />
            <geometry>
                <mesh filename="file://$(find momo_description)/meshes/visual/back_left_wheel.STL" />
            </geometry>
        </collision>
    </link>

    <gazebo reference="back_left_wheel">
        <material>Gazebo/White</material>
    </gazebo>

    <joint name="back_left_wheel_joint" type="continuous">
        <origin xyz="-0.273501168246142 0.318000000000003 0.0599931160727954" rpy="1.5707963267949 0 0" />
        <parent link="base_link" />
        <child link="back_left_wheel" />
        <axis xyz="0 0 -1" />
    </joint>

    <!-- FRONT LEFT WHEEL -->
    <link name="front_left_wheel">
        <inertial>
            <origin xyz="0.00234975130658399 0.00303912478874915 -0.00243588240434497" rpy="0 0 0" />
            <mass value="0.852354640622848" />
            <inertia ixx="0.000907516356656273" ixy="1.98922509533706E-07" ixz="-2.1406272773239E-11" iyy="0.000905483468994953" iyz="-4.08920321728966E-12" izz="0.00106934438027433" />
        </inertial>
        <visual>
            <origin xyz="0 0 0" rpy="0 0 0" />
            <geometry>
                <mesh filename="file://$(find momo_description)/meshes/visual/front_left_wheel.STL" />
            </geometry>
            <material name="">
                <color rgba="0.792156862745098 0.819607843137255 0.933333333333333 1" />
            </material>
        </visual>
        <collision>
            <origin xyz="0 0 0" rpy="0 0 0" />
            <geometry>
                <mesh filename="file://$(find momo_description)/meshes/visual/front_left_wheel.STL" />
            </geometry>
        </collision>
    </link>

    <gazebo reference="front_left_wheel">
        <material>Gazebo/White</material>
    </gazebo>

    <joint name="front_left_wheel_joint" type="continuous">
        <origin xyz="0.268493050220139 0.317999999999998 0.0599993263438537" rpy="1.5707963267949 0 0" />
        <parent link="base_link" />
        <child link="front_left_wheel" />
        <axis xyz="0 0 -1" />
    </joint>

</robot>

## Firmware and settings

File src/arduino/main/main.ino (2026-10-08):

#define Button_Color_Red 2
#define Button_Color_Green 4
#define Button_Color_Blue 7
#define BatteryWatcher_Red 5
#define BatteryWatcher_Green 6
#define voltage 7
#include "DFRobotDFPlayerMini.h"
#include <SoftwareSerial.h>
SoftwareSerial mySerial(10, 11); // RX, TX
DFRobotDFPlayerMini myMP3;

#include <Adafruit_NeoPixel.h>
#define PINLeft             3                                                                             //sets the pin on which the neopixels are connected
#define NUMPIXELSLeft       39 //defines the number of pixels in the strip
int intervalLeft = 20;       //defines the delay interval between running the functions
#define PINRight            9//sets the pin on which the neopixels are connected
#define NUMPIXELSRight      39 //defines the number of pixels in the strip
int intervalRight = 20;        //defines the delay interval between running the functions
#define PINMiddle1             12//sets the pin on which the neopixels are connected
#define NUMPIXELSMiddle1      39 //defines the number of pixels in the strip
int intervalMiddle1 = 20;        //defines the delay interval between running the functions
#define PINMiddle2            8 //sets the pin on which the neopixels are connected
#define NUMPIXELSMiddle2      39 //defines the number of pixels in the strip
int intervalMiddle2 = 20;        //defines the delay interval between running the functions

Adafruit_NeoPixel pixelsLeft = Adafruit_NeoPixel(NUMPIXELSLeft, PINLeft, NEO_GRB + NEO_KHZ800);
Adafruit_NeoPixel pixelsRight = Adafruit_NeoPixel(NUMPIXELSRight, PINRight, NEO_GRB + NEO_KHZ800);
Adafruit_NeoPixel pixelsMiddle1 = Adafruit_NeoPixel(NUMPIXELSMiddle1, PINMiddle1, NEO_GRB + NEO_KHZ800);
Adafruit_NeoPixel pixelsMiddle2 = Adafruit_NeoPixel(NUMPIXELSMiddle2, PINMiddle2, NEO_GRB + NEO_KHZ800);

//Variables for the Left side
uint32_t redLeft = pixelsLeft.Color(255, 0, 0);
uint32_t blueLeft = pixelsLeft.Color(0, 0, 255);
uint32_t greenLeft = pixelsLeft.Color(0, 255, 0);
uint32_t pixelColourLeft;
uint32_t lastColorLeft;
float activeColorLeft[] = {255, 0, 0};//sets the default color to red // used by modes 10, 12, and 13.
boolean NeoStateLeft[] = {false, false, false, false, false, false, false, false, false, false, false, false, false, false, true}; //Active Neopixel Function (off by default)
int neopixModeLeft = 0; //sets a mode to run each of the functions
long previousMillisLeft = 0; // a long value to store the millis()
long lastAllCycleLeft = 0; // last cycle in the ALL() function
long previousColorMillisLeft = 0; // timer for the last color change
int iLeft = 0; //sets the pixel number in newTheatreChase() and newColorWipe()
int CWColorLeft = 0; //sets the newColorWipe() color value 0=Red, 1=Green, 2=Blue
int jLeft; //sets the pixel to skip in newTheatreChase() and newTheatreChaseRainbow()
int cycleLeft = 0;//sets the cycle number in newTheatreChase()
int TCColorLeft = 0;//sets the color in newTheatreChase()
int lLeft = 0; //sets the color value to send to Wheel in newTheatreChaseRainbow() and newRainbow()
int mLeft = 0; //sets the color value in newRainbowCycle()
int nLeft = 2; //sets the pixel number in cyclonChaser()
int breatherLeft = 0; //sets the brightness value in breather()
boolean dirLeft = true; //sets the direction in breather()-breathing in or out, and cylonChaser()-left or right
boolean beatLeft = true; //sets the beat cycle in heartbeat()
int beatsLeft = 0; //sets the beat number in heartbeat()
int brightnessLeft = 200; //sets the default brightness value
int oLeft = 0; //christmas LED value
int qLeft = 5; // values for the All() function
uint32_t lastAllColorLeft = 0; // last color displayed in the All() function

//Variables for the Right side
uint32_t redRight = pixelsRight.Color(255, 0, 0);
uint32_t blueRight = pixelsRight.Color(0, 0, 255);
uint32_t greenRight = pixelsRight.Color(0, 255, 0);
uint32_t pixelColourRight;
uint32_t lastColorRight;
float activeColorRight[] = {255, 0, 0};//sets the default color to red
boolean NeoStateRight[] = {false, false, false, false, false, false, false, false, false, false, false, false, false, false, true}; //Active Neopixel Function (off by default)
int neopixModeRight = 0; //sets a mode to run each of the functions
long previousMillisRight = 0; // a long value to store the millis()
long lastAllCycleRight = 0; // last cycle in the ALL() function
long previousColorMillisRight = 0; // timer for the last color change
int iRight = 0; //sets the pixel number in newTheatreChase() and newColorWipe()
int CWColorRight = 0; //sets the newColorWipe() color value 0=Red, 1=Green, 2=Blue
int jRight; //sets the pixel to skip in newTheatreChase() and newTheatreChaseRainbow()
int cycleRight = 0;//sets the cycle number in newTheatreChase()
int TCColorRight = 0;//sets the color in newTheatreChase()
int lRight = 0; //sets the color value to send to Wheel in newTheatreChaseRainbow() and newRainbow()
int mRight = 0; //sets the color value in newRainbowCycle()
int nRight = 2; //sets the pixel number in cyclonChaser()
int breatherRight = 0; //sets the brightness value in breather()
boolean dirRight = true; //sets the direction in breather()-breathing in or out, and cylonChaser()-left or right
boolean beatRight = true; //sets the beat cycle in heartbeat()
int beatsRight = 0; //sets the beat number in heartbeat()
int brightnessRight = 200; //sets the default brightness value
int oRight = 0; //christmas LED value
int qRight = 5; // values for the All() function
uint32_t lastAllColorRight = 0; // last color displayed in the All() function

//Variables for the Middle2 side
uint32_t redMiddle2 = pixelsMiddle2.Color(255, 0, 0);
uint32_t blueMiddle2 = pixelsMiddle2.Color(0, 0, 255);
uint32_t greenMiddle2 = pixelsMiddle2.Color(0, 255, 0);
uint32_t pixelColourMiddle2;
uint32_t lastColorMiddle2;
float activeColorMiddle2[] = {255, 0, 0};//sets the default color to red
boolean NeoStateMiddle2[] = {false, false, false, false, false, false, false, false, false, false, false, false, false, false, true}; //Active Neopixel Function (off by default)
int neopixModeMiddle2 = 0; //sets a mode to run each of the functions
long previousMillisMiddle2 = 0; // a long value to store the millis()
long lastAllCycleMiddle2 = 0; // last cycle in the ALL() function
long previousColorMillisMiddle2 = 0; // timer for the last color change
int iMiddle2 = 0; //sets the pixel number in newTheatreChase() and newColorWipe()
int CWColorMiddle2 = 0; //sets the newColorWipe() color value 0=Red, 1=Green, 2=Blue
int jMiddle2; //sets the pixel to skip in newTheatreChase() and newTheatreChaseRainbow()
int cycleMiddle2 = 0;//sets the cycle number in newTheatreChase()
int TCColorMiddle2 = 0;//sets the color in newTheatreChase()
int lMiddle2 = 0; //sets the color value to send to Wheel in newTheatreChaseRainbow() and newRainbow()
int mMiddle2 = 0; //sets the color value in newRainbowCycle()
int nMiddle2 = 2; //sets the pixel number in cyclonChaser()
int breatherMiddle2 = 0; //sets the brightness value in breather()
boolean dirMiddle2 = true; //sets the direction in breather()-breathing in or out, and cylonChaser()-left or right
boolean beatMiddle2 = true; //sets the beat cycle in heartbeat()
int beatsMiddle2 = 0; //sets the beat number in heartbeat()
int brightnessMiddle2 = 255; //sets the default brightness value
int oMiddle2 = 0; //christmas LED value
int qMiddle2 = 5; // values for the All() function
uint32_t lastAllColorMiddle2 = 0; // last color displayed in the All() function
byte rr = 0xff; //Meteor Red
byte gg = 0xff; //Meteor Green
byte bb = 0xff; //Meteor Blue

byte ledStateLeft;
byte ledStateRight;
byte ledStateMiddle1;
byte ledStateMiddle2;

boolean alarm = false;

boolean readyFromPC = false; // set once main PC sends the ready byte over hardware Serial
boolean bereitAnnounced = false; // ensures "Ich bin bereit" plays only once

// State color reported by the PC based on the mission_control state machine.
// 0 = none received yet (fallback: white, state machine not active), 2/3/16/17/18/19/20 = see the ledStateLeft switch in f_loop.ino
byte rosColorState = 0;

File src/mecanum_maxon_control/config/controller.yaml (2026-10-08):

/**:
  ros__parameters:
    wheel_radius: 0.10
    # Calibrated MoMo geometry from the original ROS 1 controller config.
    wheelbase: 0.54
    track_width: 0.58
    # Original ros_canopen conversion used 21 motor revolutions per wheel turn.
    gear_ratio: 21.0
    # Node order: front-left, front-right, rear-left, rear-right.
    # All EPOS4 units use the same command sign on this robot.
    motor_directions: [1.0, 1.0, 1.0, 1.0]
    # Keep below the EPOS4 max profile velocity of 3170 rpm configured in the
    # motor DCF files. At 21:1 with 0.10 m wheels, 3000 rpm is about 1.50 m/s.
    max_motor_rpm: 3000.0
    max_linear_velocity: 4.0
    max_angular_velocity: 3.0
    # Accelerate at about 10000 motor rpm/s, matching the EPOS profile setting.
    # This reaches the 3000 rpm ceiling in approximately 0.3 seconds.
    max_wheel_acceleration: 1050.0
    # Stop at about 10000 motor rpm/s, matching the EPOS profile deceleration.
    # From the 3000 rpm ceiling this produces an approximately 0.3 second stop.
    max_wheel_deceleration: 1050.0
    # Zero latches the last cmd_vel until a new command is received. Keyboard
    # teleop sends an explicit zero for its stop keys (k or space).
    command_timeout: 0.0
    publish_rate: 50.0
    auto_start: true
    service_timeout: 30.0
    # The CANopen bus can still be mid-boot (config download to other nodes)
    # when this node starts. Firing 'init' at a node while the bus is busy
    # with another node's boot handshake makes the CiA402 state transition
    # time out, which can cascade into the whole device_container crashing.
    # Settle first, then retry patiently instead of giving up in ~3s.
    startup_settle_delay: 30.0
    # The retry budget has to outlast the slowest possible CANopen boot, or
    # init is abandoned on a drive that was about to come up. Observed
    # 2026-09-11: drive 3 took 59.9s to boot (the bus.yml master
    # boot_timeout: 60000 expiring) and reported ready 0.1s AFTER attempt
    # 10/10 failed -- the launch failed by a tenth of a second. bus.yml allows
    # boot_timeout_ms: 90000 per drive, so budget for more than that:
    # 30s settle + 40 * 3s = 150s. Cost is only that a genuinely dead drive
    # takes longer to be declared dead.
    startup_retries: 40
    startup_retry_delay: 3.0
    startup_drive_stagger: 2.0
    direct_can_velocity: true
    can_interface: can0
    cmd_vel_topic: cmd_vel_switched
    # odom->base_link TF broadcast from mecanum_wheel_odometry. OFF for live
    # operation: the Qualisys mocap publishes map->base_link directly, and
    # base_link cannot have two TF parents. Turn this on only for bag replay
    # with AMCL, which needs an odom->base_link edge -- and then make sure
    # qualisys_localization_node is NOT running in that session.
    # epos4_controller does not read this param, so sharing it on the /**
    # wildcard block is safe.
    publish_tf: false

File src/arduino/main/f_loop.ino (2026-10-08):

void loop() {
  while (Serial.available() > 0) {
    byte cmd = Serial.read();
    switch (cmd) {
      case 'R': readyFromPC = true; break; // main PC finished booting
      case 'G': rosColorState = 2;  break; // GREEN: autonomous mission underway
      case 'Y': rosColorState = 17; break; // YELLOW: paused / standing by
      case 'B': rosColorState = 3;  break; // BLUE: under manual/teleop control
      case 'E': rosColorState = 1;  break; // RED: gentle-stop / software emergency
      case 'W': rosColorState = 18; break; // WHITE: state machine not active yet
      case 'P': rosColorState = 19; break; // pulsing: motors booting
      case 'F': rosColorState = 20; break; // RED-ORANGE: motor driver crashed / boot failed
      case 'S': rosColorState = 21; break; // pulsing PURPLE: arm searching/scanning for a grasp
      case 'A': rosColorState = 22; break; // chasing YELLOW: arm approaching/executing a grasp
      case 'X': rosColorState = 23; break; // flashing RED: grasp failed / slipped / unreachable
      case 'K': rosColorState = 24; break; // flashing GREEN: verified grasp success
      case 'M': rosColorState = 25; break; // solid CYAN: arm under manual/joystick remote control
      default: break;
    }
  }
  if (readyFromPC && !bereitAnnounced) {
    myMP3.play(8); // "Ich bin bereit"
    bereitAnnounced = true;
  }
  pixelsLeft.setBrightness(brightnessLeft); // sets the inital brightness of the neopixels
  pixelsRight.setBrightness(brightnessRight); // sets the inital brightness of the neopixels
  int analog_BatteryWatcher_Green = analogRead(BatteryWatcher_Green);
  int analog_BatteryWatcher_Red = analogRead(BatteryWatcher_Red);
  int analog_voltage = analogRead(voltage);
  //Serial.println(analog_voltage);
  delay(50);
  if ((analog_BatteryWatcher_Red>500) && (analog_BatteryWatcher_Green<500)){ // Shutdown
    digitalWrite(Button_Color_Red, HIGH); digitalWrite(Button_Color_Green, LOW); digitalWrite(Button_Color_Blue, LOW);
    ledStateLeft = 1; ledStateRight = 1;
    delay(100);
     }
  if ((analog_BatteryWatcher_Green>500) && (analog_BatteryWatcher_Red<500) && (analog_voltage<500)){ // no alarm
     digitalWrite(Button_Color_Red, LOW); digitalWrite(Button_Color_Blue, HIGH);
     myMP3.stop();
     ledStateLeft = (rosColorState != 0) ? rosColorState : 18; // mission state color from PC, WHITE until the state machine is active
     ledStateRight = ledStateLeft;
     alarm = true;
     delay(100);
     }
  if ((analog_BatteryWatcher_Red>500) && (analog_BatteryWatcher_Green>500) && (analog_voltage<500)){ // battery warning
     digitalWrite(Button_Color_Red, HIGH); digitalWrite(Button_Color_Green, LOW); digitalWrite(Button_Color_Blue, LOW);
     ledStateLeft = 16; ledStateRight = 16; // ORANGE: battery warning
     //delay(20); alarm = true;
     myMP3.loop(3);
     delay(100);
    }
  if ((analog_BatteryWatcher_Red<500) && (analog_BatteryWatcher_Green>500) && (analogRead(voltage)>500)){ // e-stop active
     digitalWrite(Button_Color_Red, HIGH); digitalWrite(Button_Color_Blue, LOW);
     if (alarm==true){myMP3.play(9); alarm = false;}
     ledStateLeft = 1; ledStateRight = 1;
     delay(100);
    }
  switch (ledStateLeft) { // LED LEFT
    case 1:
      flashingLeft();//flash RED (gentle-stop / emergency) -- accessibility: never rely on solid red/green alone
      break;
    case 2:
      writeLEDSLeft(0, 255, 0);//write GREEN to all pixels
      break;
    case 3:
      writeLEDSLeft(0, 0, 255);//write BLUE to all pixels
      break;
    case 4:
      ALLLeft();
      break;
    case 5:
      newColorWipeLeft();
      break;
    case 6:
      newTheatreChaseLeft();
      break;
    case 7:
      newRainbowLeft();
      break;
    case 8:
      writeLEDSLeft(85, 85, 85);
      break;
    case 9:
      newTheatreChaseRainbowLeft();
      break;
    case 10:
      colorCyclerLeft();
      cylonChaserLeft();
      break;
    case 11:
      newRainbowCycleLeft();
      break;
    case 12:
      colorCyclerLeft();
      breathingLeft();
      break;
    case 13:
      colorCyclerLeft();
      heartbeatLeft();
      break;
    case 14:
      christmasChaseLeft();
      break;
    case 15:
      FireLeft();
      break;
    case 16:
      writeLEDSLeft(255, 140, 0);//write ORANGE to all pixels (battery warning)
      break;
    case 17:
      writeLEDSLeft(255, 255, 0);//write YELLOW to all pixels (paused/standby)
      break;
    case 18:
      writeLEDSLeft(255, 255, 255);//write WHITE to all pixels (state machine not active yet)
      break;
    case 19:
      activeColorLeft[0] = 255; activeColorLeft[1] = 255; activeColorLeft[2] = 255;
      breathingLeft(); //pulse WHITE (motors booting)
      break;
    case 20:
      writeLEDSLeft(255, 60, 0);//write RED-ORANGE to all pixels (motor driver crashed / boot failed)
      break;
    case 21:
      activeColorLeft[0] = 150; activeColorLeft[1] = 0; activeColorLeft[2] = 255;
      breathingLeft(); //pulse PURPLE (arm searching/scanning)
      break;
    case 22:
      TCColorLeft = 4;
      newTheatreChaseLeft(); //chase YELLOW (arm approaching/executing)
      break;
    case 23:
      flashingLeft(); //flash RED (grasp failed/slipped/unreachable)
      break;
    case 24:
      flashingGreenLeft(); //flash GREEN (verified grasp success)
      break;
    case 25:
      writeLEDSLeft(0, 255, 255); //write CYAN (arm under manual/joystick remote control)
      break;
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

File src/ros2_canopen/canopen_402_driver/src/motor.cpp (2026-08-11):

//    Copyright 2023 Christoph Hellmann Santos
//    Copyright 2023 Vishnuprasad Prachandabhanu
//    Copyright 2014-2022 Authors of ros_canopen
//
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

#include "canopen_402_driver/motor.hpp"
using namespace ros2_canopen;

bool Motor402::setTarget(double val)
{
  if (state_handler_.getState() == State402::Operation_Enable)
  {
    std::scoped_lock lock(mode_mutex_);
    return selected_mode_ && selected_mode_->setTarget(val);
  }
  return false;
}
bool Motor402::isModeSupported(uint16_t mode)
{
  return mode != MotorBase::Homing && allocMode(mode);
}

bool Motor402::enterModeAndWait(uint16_t mode)
{
  bool okay = mode != MotorBase::Homing && switchMode(mode);
  return okay;
}

uint16_t Motor402::getMode()
{
  std::scoped_lock lock(mode_mutex_);
  return selected_mode_ ? selected_mode_->mode_id_ : (uint16_t)MotorBase::No_Mode;
}

bool Motor402::isModeSupportedByDevice(uint16_t mode)
{
  uint32_t supported_modes =
    driver->universal_get_value<uint32_t>(supported_drive_modes_index, 0x0);
  bool supported = supported_modes & (1 << (mode - 1));
  bool below_max = mode <= 32;
  bool above_min = mode > 0;
  return below_max && above_min && supported;
}
void Motor402::registerMode(uint16_t id, const ModeSharedPtr & m)
{
  std::scoped_lock map_lock(map_mutex_);
  if (m && m->mode_id_ == id) modes_.insert(std::make_pair(id, m));
}

ModeSharedPtr Motor402::allocMode(uint16_t mode)
{
  ModeSharedPtr res;
  if (isModeSupportedByDevice(mode))
  {
    std::scoped_lock map_lock(map_mutex_);
    std::unordered_map<uint16_t, ModeSharedPtr>::iterator it = modes_.find(mode);
    if (it != modes_.end())
    {
      res = it->second;
    }
  }
  return res;
}

bool Motor402::switchMode(uint16_t mode)
{
  if (mode == MotorBase::No_Mode)
  {
    std::scoped_lock lock(mode_mutex_);
    selected_mode_.reset();
    try
    {  // try to set mode
      driver->universal_set_value<int8_t>(op_mode_index, 0x0, mode);
    }
    catch (...)
    {
    }
    if (enable_diagnostics_.load())
    {
      this->diag_collector_->addf("cia402_mode", "No mode selected: %d", mode);
    }
    return true;
  }

  ModeSharedPtr next_mode = allocMode(mode);
  if (!next_mode)
  {
    RCLCPP_INFO(rclcpp::get_logger("canopen_402_driver"), "Mode is not supported.");
    return false;
  }

  if (!next_mode->start())
  {
    RCLCPP_INFO(rclcpp::get_logger("canopen_402_driver"), "Could not  start mode.");
    return false;
  }

  {  // disable mode handler
    std::scoped_lock lock(mode_mutex_);

    if (mode_id_ == mode && selected_mode_ && selected_mode_->mode_id_ == mode)
    {
      // nothing to do
      return true;
    }

    selected_mode_.reset();
  }

  if (!switchState(switching_state_)) return false;

  driver->universal_set_value<int8_t>(op_mode_index, 0x0, mode);

  bool okay = false;

  {  // wait for switch
    std::unique_lock lock(mode_mutex_);

    std::chrono::steady_clock::time_point abstime =
      std::chrono::steady_clock::now() + std::chrono::seconds(5);
    if (monitor_mode_)
    {
      while (mode_id_ != mode && mode_cond_.wait_until(lock, abstime) == std::cv_status::no_timeout)
      {
      }
    }
    else
    {
      while (mode_id_ != mode && std::chrono::steady_clock::now() < abstime)
      {
        lock.unlock();                                                    // unlock inside loop
        driver->universal_get_value<int8_t>(op_mode_display_index, 0x0);  // poll
        std::this_thread::sleep_for(std::chrono::milliseconds(20));       // wait some time
        lock.lock();
      }
    }

    if (mode_id_ == mode)
    {
      selected_mode_ = next_mode;
      okay = true;
      if (enable_diagnostics_.load())
      {
        this->diag_collector_->addf("cia402_mode", "Mode switched to: %d", mode);
      }
    }
    else
    {
      RCLCPP_INFO(rclcpp::get_logger("canopen_402_driver"), "Mode switch timed out.");
      driver->universal_set_value<int8_t>(op_mode_index, 0x0, mode_id_);
      if (enable_diagnostics_.load())
      {
        this->diag_collector_->addf("cia402_mode", "Mode switch timed out: %d", mode);
      }
    }
  }

  if (!switchState(State402::Operation_Enable)) return false;

  return okay;
}

bool Motor402::switchState(const State402::InternalState & target)
{
  std::chrono::steady_clock::time_point abstime =
    std::chrono::steady_clock::now() + state_switch_timeout_;
  State402::InternalState state = state_handler_.getState();
  target_state_ = target;
  while (state != target_state_)
  {
    std::unique_lock lock(cw_mutex_);
    State402::InternalState next = State402::Unknown;
    bool success = Command402::setTransition(control_word_, state, target_state_, &next);
    if (!success)
    {
      RCLCPP_INFO(rclcpp::get_logger("canopen_402_driver"), "Could not set transition.");
      return false;
    }
    else if (enable_diagnostics_.load() && success)
    {
      this->diag_collector_->addf("cia402_state", "State switched to: %d", next);
    }
    lock.unlock();
    if (state != next && !state_handler_.waitForNewState(abstime, state))
    {
      RCLCPP_INFO(rclcpp::get_logger("canopen_402_driver"), "Transition timed out.");
      if (enable_diagnostics_.load())
      {
        this->diag_collector_->addf(
          "cia402_state", "State transition timed out: %d -> %d", state, next);
      }
      return false;
    }
  }
  return state == target;
}

bool Motor402::readState()
{
  uint16_t old_sw, sw = driver->universal_get_value<uint16_t>(
                     status_word_entry_index, 0x0);  // TODO: added error handling
  old_sw = status_word_.exchange(sw);

  state_handler_.read(sw);

  std::unique_lock lock(mode_mutex_);
  uint16_t new_mode;
  new_mode = driver->universal_get_value<int8_t>(op_mode_display_index, 0x0);
  // RCLCPP_INFO(rclcpp::get_logger("canopen_402_driver"), "Mode %hhi",new_mode);

  if (selected_mode_ && selected_mode_->mode_id_ == new_mode)
  {
    if (!selected_mode_->read(sw))
    {
      RCLCPP_INFO(rclcpp::get_logger("canopen_402_driver"), "Mode handler has error.");
    }
  }
  if (new_mode != mode_id_)
  {
    mode_id_ = new_mode;
    mode_cond_.notify_all();
  }
  if (selected_mode_ && selected_mode_->mode_id_ != new_mode)
  {
    RCLCPP_INFO(rclcpp::get_logger("canopen_402_driver"), "Mode does not match.");
  }
  if (sw & (1 << State402::SW_Internal_limit))
  {
    if (old_sw & (1 << State402::SW_Internal_limit))
    {
      RCLCPP_INFO(rclcpp::get_logger("canopen_402_driver"), "Internal limit active");
    }
    else
    {
      RCLCPP_INFO(rclcpp::get_logger("canopen_402_driver"), "Internal limit active");
    }
  }

  return true;
}
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

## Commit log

2024-07-18 Move project from GitLab to GitHub
    [Aluminium_angle_bracket.SLDPRT, Aluminium_profile_160.SLDPRT, Aluminium_profile_30.SLDPRT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]
2024-07-18 Update momo_description for perception module
    [back_logitech.STL, front_logitech.STL, ifm_camera.STL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]
2024-08-29 save changes before switching branches
    [momo.urdf.xacro, momo_core.xacro, momo_perception_module.xacro]
2024-08-31 Update mesh file path syntax
    [momo_core.xacro, momo_perception_module.xacro]
2024-08-31 Add gazebo colors
    [momo_core.xacro, momo_perception_module.xacro]
2024-08-31 Add gazebo planar plugin
    [gazebo_contro.xacro, momo.urdf.xacro]
2024-08-31 Add gazebo laser plugin to simulation
    [lidar_plugin.xacro, momo.urdf.xacro]
2024-09-01 Add front camera plugin
    [camera_plugin.xacro, momo.urdf.xacro, momo_perception_module.xacro]
2024-09-01 Add remaining camera plugins for gazebo
    [camera_plugin.xacro, momo_perception_module.xacro]
2024-09-04 Add depth camera plugin
    [depth_camera_plugin.xacro, momo.urdf.xacro, momo_perception_module.xacro]
2024-09-04 Disable lidar visualization in Gazebo
    [lidar_plugin.xacro]
2024-09-04 Fix camera orientation
    [momo_perception_module.xacro]
2024-09-04 Fix frame position
    [momo_core.xacro, momo_perception_module.xacro]
2024-09-04 Rotate lidar by 90 degrees
    [momo_perception_module.xacro]
2024-09-08 Add gazebo joint state publisher plugin
    [gazebo_control.xacro]
2024-09-09 Change frame name laser_frame -> lidar
    [lidar_plugin.xacro]
2024-09-13 Update robot footprint
2024-09-25 Rename lidar wheel ekf config file
2026-08-11 Upgrade to Jazzy
    [back_logitech.STL, base_link.STL, camera_plugin.xacro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]
2026-08-19 Add dual TiM5xx lidar bringup, mocap-scenario Nav2 config, and omni teleop
    - New tim_lidars.launch.py: launches both TiM5xx units (192.168.0.41 and
    192.168.1.42, the latter re-IP'd off a shared subnet) with measured
    base_link TF offsets, wired into start_up.launch.py.
    - New nav2_params_mocap.yaml: no-AMCL Nav2 config for the qualisys mocap
    localization scenario, tuned MPPI/critics for the mecanum platform and
    this machine's measured compute budget.
    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
    [camera_plugin.xacro, controller.yaml, depth_camera_plugin.xacro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]
2026-08-27 Switch MoMo to mocap-based localization, drop legacy nav2/EKF stack
    Bump robotics_base submodule (mocap qualisys_localization state-machine
    wiring, generic pose_input_topic, API 33.0.0). Add master-control-connected
    and ranger master-control launch files, and a standalone momo_description
    launch file (joint_state_publisher instead of the *_gui variant). Add
    mecanum wheel odometry node, raise EPOS4 boot timeout margin, and make
    CANopen driver boot-retry/init failures non-fatal to the rest of the bus.
    Update TiM lidar hostnames, mocap factsheet dimensions/actions, and remove
    the now-unused differential-drive nav2/EKF/slam_toolbox launch and config
    files from momo_navigation.
    [mecanum_wheel_odometry.py]
2026-10-08 Add SLAM mapping, Arduino status indicator, and drive/launch updates
    - Add slam_toolbox mocap config, slam_mapping launch file, and lab maps
    - Add Arduino status indicator script and rework Arduino firmware
    - Update mecanum drive controller, launch, bus config, and README
    - Add CAN capabilities helper script for canopen_core
    - Adjust startup and lidar launch files
    [controller.yaml]
2026-10-08 Bump robotics_base and mocap4ros2_qualisys submodules
    - robotics_base: momo/integration (manipulation, qualisys rigid body by name,
    shutdown on node crash)
    - mocap4ros2_qualisys: activate driver only after configure completes

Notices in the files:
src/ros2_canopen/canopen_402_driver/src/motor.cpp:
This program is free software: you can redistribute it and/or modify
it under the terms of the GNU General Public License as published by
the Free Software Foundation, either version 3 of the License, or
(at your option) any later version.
